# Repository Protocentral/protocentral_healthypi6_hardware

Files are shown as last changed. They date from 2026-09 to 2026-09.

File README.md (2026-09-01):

<div align="center">

<picture>
  <source media="(prefers-color-scheme: dark)" srcset="docs/images/healthypi6-logo-dark.png">
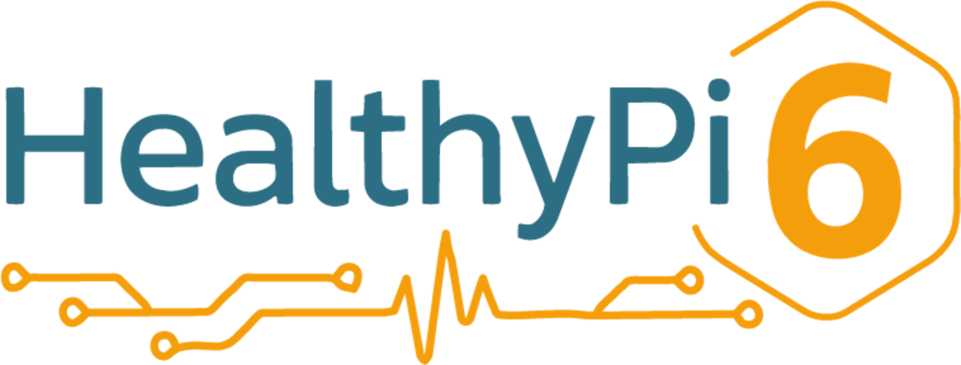
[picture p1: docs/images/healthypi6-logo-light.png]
HealthyPi 6
  
</picture>

</div>

# HealthyPi 6 — Hardware

Open hardware design files for HealthyPi 6, a standalone vital-signs monitor with a
modular expansion bus.

The device is built around a tri-core architecture — an STM32H757BI (Cortex-M7 +
Cortex-M4) with an ESP32-C6 for wireless — with a 4" capacitive touchscreen, an isolated
supply, an isolated USB port, and two HealthyLink expansion slots that accept new sensing
front-ends without a board respin.

This repository holds the KiCad schematics and PCB layouts, the HealthyLink interface
definition, the enclosure CAD, and the CE/UKCA declarations of conformity.

## Links

| | |
|---|---|
| Product page | https://www.crowdsupply.com/protocentral/healthypi-6 |
| Firmware (Zephyr) | https://github.com/Protocentral/healthypi-6-fw |
| HealthyPi Studio | https://github.com/Protocentral/healthypi_studio |

## Boards

Design files are published as each board is finalised.

| Board | Revision | Role |
|---|---|---|
| [`healthypi_6_main_v5`](hardware/healthypi_6_main_v5/) | **v5** | STM32H757BI main board — AFEs, power, wireless, both HealthyLink slots |
| [`healthypi_6_display_v7`](hardware/healthypi_6_display_v7/) | **v7** | Display interface board — MIPI-DSI and touch to the panel, backlight driver |
| [`healthylink_compute_v5`](hardware/healthylink_compute_v5/) | **v5** | HealthyLink compute / NPU module — STM32N657, camera, storage |
| [`healthylink_gpio_v2`](hardware/healthylink_gpio_v2/) | **v2** | HealthyLink GPIO breakout — the minimal module example |

## Specifications

Cross-checked against the v5 schematic in this repository.

- **Application processor:** STM32H757BI (LQFP208) — Arm Cortex-M7 @ 400 MHz +
  Cortex-M4 @ 200 MHz
- **Wireless:** ESP32-C6-MINI-1 (Wi-Fi 6 / BLE / 802.15.4), UART and SPI to the host MCU,
  plus its own USB-C for direct flashing
- **Display:** 4" 480×800 capacitive touchscreen — 2-lane MIPI-DSI, touch on I²C,
  TPS61158 backlight boost on the display board
- **Biosignal front-ends:** TI ADS1294R (ECG + thoracic respiration), TI AFE4400 (PPG),
  Bosch BMI323 (motion)
- **Expansion:** 2 × HealthyLink slots, 2 × Hirose DF9-31P-1V per slot (62 pins/slot),
  per-slot NCP380 current-limited load switch with fault reporting
- **Power:** isolated 10 W supply (Traco THM 10-0511); TI BQ24074 linear battery charger,
  Maxim MAX17048 fuel gauge, TPS62A02 system buck
- **Memory and storage:** 32 MB SDRAM (Winbond W9825G6KH), 64 MB QSPI NOR
  (Winbond W25Q512JV), microSD
- **Host interface:** USB-C, USB 2.0 full-speed, galvanically isolated through a
  TI ISOUSB111
- **Main board:** 120 × 70 mm, 6-layer

## HealthyLink expansion bus

HealthyLink is the modular expansion system for HealthyPi 6. Each slot presents 62 pins
across two Hirose DF9-31 board-to-board connectors, carrying two SPI buses, I²C, a UART,
six analog inputs, CAN, per-slot interrupt and reset, and a switched 3V3 module rail. The
main board has two slots (A and B).

Modules are **not hot-swappable** — install them with the device powered off.

The full pin assignment and electrical definition is in
[`docs/HEALTHYLINK.md`](docs/HEALTHYLINK.md). The KiCad symbol for the connector is
[`hardware/healthylink_df9_connector.kicad_sym`](hardware/healthylink_df9_connector.kicad_sym) —
use it as the starting point for your own module.

## Enclosure

[`enclosure/`](enclosure/) holds the CAD for the case, in three forms: the editable
Fusion archive, a neutral STEP export per part, and a print-ready STL per part.

| Part | Size |
|---|---|
| `top` | 125 × 75 × 23 mm |
| `bottom` | 125 × 75 × 14 mm |
| `back-cover-with-slots` | 125 × 75 × 3 mm |
| `back-cover-no-slots` | 125 × 75 × 7.5 mm |
| `battery-holder` | 53 × 35 × 14 mm |
| `push-switch` | 8 × 5 × 4 mm |
| `slide-switch` | 7 × 13 × 5 mm |

Every part appears under the same name in both
[`enclosure/step/`](enclosure/step/) and [`enclosure/stl/`](enclosure/stl/). The Fusion
source is [`enclosure/source/healthypi6-enclosure-v5.f3z`](enclosure/source/); open it if
you want to change the geometry rather than print it as-is. The enclosure is drawn around
the 120 × 70 mm main board, so any board modification that moves a connector or a mounting
hole needs a matching change here.

## Repository layout

| Path | Contents |
|---|---|
| [`hardware/`](hardware/) | One folder per board: KiCad project (schematic + PCB) and exported schematic PDF |
| [`docs/`](docs/) | HealthyLink interface definition and images |
| [`enclosure/`](enclosure/) | Enclosure CAD — Fusion source, STEP and STL per part |
| [`compliance/`](compliance/) | CE and UKCA declarations of conformity, safety insert |

## Working from these files

- For firmware, start at the firmware repository. This repo is the electrical reference:
  pin assignments, AFE wiring, connector pinouts.
- To build a HealthyLink module, read [`docs/HEALTHYLINK.md`](docs/HEALTHYLINK.md) and
  copy [`healthylink_gpio_v2`](hardware/healthylink_gpio_v2/), which is the minimal
  working example.
- To respin a board: both projects are saved in **KiCad 10** format and will not open in
  earlier versions. Footprints are embedded in the board files and symbols are cached in
  the schematics, so the projects open standalone. A handful of 3D models resolve through
  an internal `${PROTOCENTRAL}` path and will show as missing in the 3D viewer; this
  affects rendering only, never the netlist or the layout.

## Important notice

This device is intended for **research, education, and evaluation use only**. It is **not**
a medical diagnostic instrument, and it is not FDA-approved or otherwise cleared for
clinical or consumer diagnostic use. The CE and UKCA declarations in
[`compliance/`](compliance/) cover EMC and electrical safety for the device as an
electronic product — they are not medical device certifications.

Do not use HealthyPi 6 to make medical decisions.

## License

The hardware design files in this repository are licensed under the **CERN Open Hardware
Licence Version 2 – Permissive (CERN-OHL-P v2)**. See [LICENSE](LICENSE).

Firmware and software for HealthyPi 6 are licensed separately under the MIT License in
their own repositories.

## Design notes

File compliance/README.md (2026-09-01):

# Compliance

| Document | Covers |
|---|---|
| [`healthypi6-ce-doc.pdf`](healthypi6-ce-doc.pdf) | EU Declaration of Conformity |
| [`healthypi6-ukca-doc.pdf`](healthypi6-ukca-doc.pdf) | UKCA Declaration of Conformity |
| [`healthypi6-safety-insert.pdf`](healthypi6-safety-insert.pdf) | A6 safety insert shipped in the box |

These declarations cover HealthyPi 6 as an **electronic product** — EMC and electrical
safety. They are **not** medical device certifications. HealthyPi 6 is not cleared for
clinical or consumer diagnostic use. See the notice in the [top-level README](../README.md).

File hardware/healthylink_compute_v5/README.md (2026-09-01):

# HealthyLink Compute Module

| | |
|---|---|
| Revision | **v5** |
| Role | HealthyLink compute / NPU module — STM32N657 with camera and storage |
| Board | 50 × 60 mm, 6-layer |
| Slot | Occupies one HealthyLink slot (J5) |
| KiCad | 10 |
| Schematic PDF | [`healthylink-compute-v5-schematic.pdf`](healthylink-compute-v5-schematic.pdf) |

## Files

| File | Contents |
|---|---|
| `healthylink_compute_v5.kicad_pro` / `.kicad_sch` / `.kicad_pcb` | KiCad project for this revision |
| `healthylink-compute-v5-schematic.pdf` | Exported schematic — the human-readable reference |

## Schematic sheets

Sheet names and filenames do not line up on this project; the table gives both.

| Sheet | File | Contents |
|---|---|---|
| *(root)* | `healthylink_compute_v5.kicad_sch` | HealthyLink connector, AT24CS02 ID EEPROM, write-protect jumper |
| MCU | `mcu.kicad_sch` | STM32N657I0H3Q, MX25UM51245G octal flash, boot configuration, 32.768 kHz |
| MCU2 | `mcu2.kicad_sch` | 48 MHz oscillator, status LEDs, debug header |
| MCU3 | `power.kicad_sch` | STM32N657 power pins and decoupling |
| power | `sys_power.kicad_sch` | TPS2116 power mux, 3 × TPS62A02 bucks, TLV75518 LDO |
| connectivity | `connectivity.kicad_sch` | microSD, USB-C, MIPI-CSI camera header |

## Bus usage

Of the HealthyLink signals, this module uses `SPI4` (`CS_1`), `I2C3`, `USART2`,
`MOD_IRQ_N`, `MOD_RESET_N` and the stacking bus. See
[`docs/HEALTHYLINK.md`](../../docs/HEALTHYLINK.md) for the full pinout.

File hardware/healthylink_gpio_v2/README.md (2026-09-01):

# HealthyLink GPIO Module

| | |
|---|---|
| Revision | **v2** |
| Role | HealthyLink GPIO breakout — the minimal module example |
| Board | 50 × 62.2 mm, 2-layer |
| Slot | Occupies one HealthyLink slot (J5) |
| KiCad | 10 |
| Schematic PDF | [`healthylink-gpio-v2-schematic.pdf`](healthylink-gpio-v2-schematic.pdf) |

## Files

| File | Contents |
|---|---|
| `healthylink_gpio_v2.kicad_pro` / `.kicad_sch` / `.kicad_pcb` | KiCad project for this revision |
| `healthylink-gpio-v2-schematic.pdf` | Exported schematic — the human-readable reference |

## What it does

A single-sheet board that brings the HealthyLink bus out to two 2×10 headers. It is the
smallest complete module in this repository and the recommended starting point for your
own design: it shows the three things every module needs and nothing else.

- **Connector** — one `HEALTHYLINK_DF9_DUAL` (J5), the two DF9-31 receptacles of one slot
- **Identification** — AT24CS02 EEPROM on `I2C3`, with a write-protect solder jumper
- **Power** — a TPS62A02 buck off the module rail

Both SPI buses, `I2C3`, `USART2`, the six analog inputs, CAN, the stacking bus and the
per-slot interrupt and reset all reach the headers. See
[`docs/HEALTHYLINK.md`](../../docs/HEALTHYLINK.md) for the pinout.

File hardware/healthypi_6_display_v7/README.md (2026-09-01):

# HealthyPi 6 Display Board

| | |
|---|---|
| Revision | **v7** |
| Role | Display interface — routes MIPI-DSI and touch I²C from the main board to the 4" panel, and drives the backlight |
| Board | 60 × 33 mm, 2-layer |
| KiCad | 10 |
| Schematic PDF | [`healthypi6-display-v7-schematic.pdf`](healthypi6-display-v7-schematic.pdf) |

## Files

| File | Contents |
|---|---|
| `healthypi_6_display_v7.kicad_pro` / `.kicad_sch` / `.kicad_pcb` | KiCad project for this revision |
| `healthypi6-display-v7-schematic.pdf` | Exported schematic — the human-readable reference |

## Interfaces

- 24-way FFC to the main board: 2-lane MIPI-DSI, touch I²C (`TP_SCL` / `TP_SDA`,
  `TP_INT`, `TP_RST`), panel reset and tearing-effect (`MIPI_RST`, `MIPI_TE`)
- TPS61158 boost driving the panel backlight, enabled by `MIPI_BKL`
- 12-way connector to the display panel

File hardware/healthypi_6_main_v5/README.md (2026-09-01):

# HealthyPi 6 Main Board

| | |
|---|---|
| Revision | **v5** |
| Role | STM32H757BI host, AFEs, power, wireless, 2 × HealthyLink slots |
| Board | 120 × 70 mm, 6-layer |
| KiCad | 10 |
| Schematic PDF | [`healthypi6-main-v5-schematic.pdf`](healthypi6-main-v5-schematic.pdf) |

## Files

| File | Contents |
|---|---|
| `healthypi_6_v5.kicad_pro` / `.kicad_sch` / `.kicad_pcb` | KiCad project for this revision |
| `healthypi6-main-v5-schematic.pdf` | Exported schematic — the human-readable reference |

## Schematic sheets

| Sheet | File | Contents |
|---|---|---|
| MCU | `mcu.kicad_sch` | STM32H757BI, clocks, SWD, buttons, buzzer |
| ECG Frontend | `ecg_afe.kicad_sch` | TI ADS1294R, ECG input protection |
| PPG Frontend | `ppg_sensor.kicad_sch` | TI AFE4400, Bosch BMI323, DE9 patient connector |
| Memory | `memory.kicad_sch` | SDRAM, QSPI NOR, microSD |
| USB | `io.kicad_sch` | USB-C, ISOUSB111 isolator, isolated 10 W supply |
| Power | `power.kicad_sch` | Battery charger, fuel gauge, system rails |
| Power 2 | `power2.kicad_sch` | Per-slot HealthyLink load switches |
| Wireless | `wireless.kicad_sch` | ESP32-C6-MINI-1 and its USB-C |
| connectors | `connectors.kicad_sch` | Display FFC, front-panel and auxiliary connectors |
| healthylink | `healthylink.kicad_sch` | Both HealthyLink slots — see [`docs/HEALTHYLINK.md`](../../docs/HEALTHYLINK.md) |

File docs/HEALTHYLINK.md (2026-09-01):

<div align="center">

<picture>
  <source media="(prefers-color-scheme: dark)" srcset="images/healthylink-logo-dark.png">
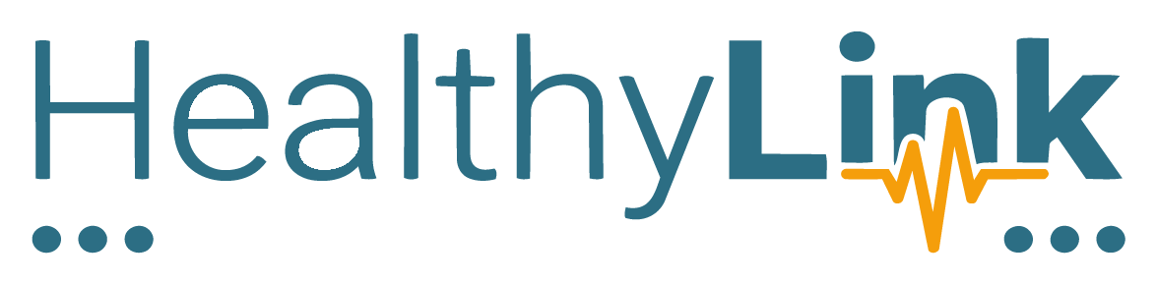
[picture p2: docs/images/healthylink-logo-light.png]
HealthyLink
  
</picture>

</div>

# HealthyLink — Interface Definition

HealthyLink is the modular expansion bus on HealthyPi 6. It lets the device gain new
sensing front-ends — EEG, compute, GPIO, your own — without respinning the main board.

Everything below is taken from the **v5 main board** schematic in this repository, which
is the shipping host design.

## Electrical overview

| | |
|---|---|
| Connector | Hirose **DF9-31P-1V(32)**, 2 per slot (Primary + Secondary) |
| Pins per slot | 62 |
| Slots on main board | 2 (Slot A, Slot B) |
| Module rail | Switched 3V3 per slot (`VDD_MOD`) through an NCP380 current-limited load switch |
| Always-on rail | `VDD_MOD_AON`, present whenever the device is powered |
| Rail control | Host-side `LDO_EN_MOD_A` / `LDO_EN_MOD_B`; fault flags `MOD_A_FLT` / `MOD_B_FLT` |
| Per-slot interrupt | `MOD_IRQ_N` — `MOD_IRQ_A` / `MOD_IRQ_B` on the host |
| Per-slot reset | `MOD_RESET_N` — `MOD_RESET_A` / `MOD_RESET_B` on the host |
| Module identification | I²C EEPROM on `I2C3`, read during a power-sequenced bus scan |
| Hot-swap | **Not supported.** Install modules with the device powered off. |

Both slots share `SPI4`, `SPI6`, `I2C3`, `USART2`, the analog inputs, the stacking bus and
CAN. Only the interrupt, reset and rail control are per-slot.

## Pinout

Directions are given **from the host's point of view**. Each slot is two DF9-31
connectors: pins 1–31 on the Primary, pins 32–62 on the Secondary.

### Primary connector (pins 1–31)

| Pin | Signal | Direction | Notes |
|---:|---|---|---|
| 1 | `VDD_MOD` | Power | Switched 3V3 module rail |
| 2 | `VDD_MOD` | Power | |
| 3 | `VDD_MOD` | Power | |
| 4 | `VDD_MOD` | Power | |
| 5 | `SPI4_SCK` | Host → Module | Primary SPI bus |
| 6 | `GND` | Power | |
| 7 | `SPI4_MOSI` | Host → Module | |
| 8 | `GND` | Power | |
| 9 | `SPI4_MISO` | Module → Host | |
| 10 | `GND` | Power | |
| 11 | `SPI4_CS_1` | Host → Module | Chip select 1 |
| 12 | `RSVD` | — | Reserved, do not connect |
| 13 | `SPI4_CS_2` | Host → Module | Chip select 2 |
| 14 | `RSVD` | — | Reserved, do not connect |
| 15 | `I2C3_SCL` | Bidirectional | Module ID EEPROM and module I²C devices |
| 16 | `RSVD` | — | Reserved, do not connect |
| 17 | `I2C3_SDA` | Bidirectional | |
| 18 | `RSVD` | — | Reserved, do not connect |
| 19 | `USART2_TX` | Host → Module | |
| 20 | `AGND` | Power | Analog ground |
| 21 | `USART2_RX` | Module → Host | |
| 22 | `AGND` | Power | |
| 23 | `USART2_RTS` | Host → Module | |
| 24 | `AGND` | Power | |
| 25 | `USART2_CTS` | Module → Host | |
| 26 | `AGND` | Power | |
| 27 | `MOD_IRQ_N` | Module → Host | Per-slot interrupt, active low |
| 28 | `VDD_MOD_AON` | Power | Always-on module rail |
| 29 | `MOD_RESET_N` | Host → Module | Per-slot reset, active low |
| 30 | `GND` | Power | |
| 31 | `GND` | Power | |

### Secondary connector (pins 32–62)

| Pin | Signal | Direction | Notes |
|---:|---|---|---|
| 32 | `VDD_MOD` | Power | |
| 33 | `GND` | Power | |
| 34 | `VDD_MOD` | Power | |
| 35 | `GND` | Power | |
| 36 | `SPI6_SCK` | Host → Module | Secondary SPI bus |
| 37 | `GND` | Power | |
| 38 | `SPI6_MOSI` | Host → Module | |
| 39 | `GND` | Power | |
| 40 | `SPI6_MISO` | Module → Host | |
| 41 | `GND` | Power | |
| 42 | `SPI6_CS_1` | Host → Module | Chip select 1 |
| 43 | `RSVD` | — | Reserved, do not connect |
| 44 | `SPI6_CS_2` | Host → Module | Chip select 2 |
| 45 | `STACK_SCK` | Module ↔ Module | Stacking bus, not driven by the host |
| 46 | `HL_ADC_CH0` | Module → Host | Analog input |
| 47 | `STACK_MOSI` | Module ↔ Module | |
| 48 | `HL_ADC_CH1` | Module → Host | |
| 49 | `STACK_MISO` | Module ↔ Module | |
| 50 | `HL_ADC_CH2` | Module → Host | |
| 51 | `STACK_CS` | Module ↔ Module | |
| 52 | `HL_ADC_CH3` | Module → Host | |
| 53 | `MOD_ADDR` | Module → Host | Module address strap |
| 54 | `HL_ADC_CH4` | Module → Host | |
| 55 | `AUX_GPIO0` | Bidirectional | General-purpose |
| 56 | `HL_ADC_CH5` | Module → Host | |
| 57 | `AUX_GPIO1` | Bidirectional | |
| 58 | `FDCAN1_TX` | Host → Module | |
| 59 | `AUX_GPIO2` | Bidirectional | |
| 60 | `FDCAN1_RX` | Module → Host | |
| 61 | `NC` | — | Not connected |
| 62 | `GND` | Power | |

The connector shells carry mounting pins (`MP`) which are tied to ground on the main board.

## Power sequencing

A slot's `VDD_MOD` rail comes up only when the host asserts that slot's enable
(`LDO_EN_MOD_A` / `LDO_EN_MOD_B`). The load switch reports over-current back to the host on
`MOD_A_FLT` / `MOD_B_FLT`, so a shorted module is detected and the slot stays down.

`VDD_MOD_AON` is not switched. Draw only what a module needs to stay identifiable while
its main rail is off.

## Module identification

Modules are identified by an **EEPROM on I²C3**, not by strapping GPIOs. The host powers a
slot, scans the bus, reads the module's identity from its EEPROM, and loads the matching
driver. Earlier designs used dedicated `MOD_ID` pins; those were freed, and the EEPROM is
now the identification path.

## Reference modules

| Module | What it adds |
|---|---|
| [`healthylink_gpio_v2`](../hardware/healthylink_gpio_v2/) | Plain GPIO breakout — the minimal example |
| [`healthylink_compute_v5`](../hardware/healthylink_compute_v5/) | STM32N657 compute / NPU module with camera and storage |

## Building your own module

1. Start from [`healthylink_gpio_v2`](../hardware/healthylink_gpio_v2/) — the smallest
   complete module in this repo — or use the connector symbol at
   [`hardware/healthylink_df9_connector.kicad_sym`](../hardware/healthylink_df9_connector.kicad_sym),
   which carries a host and a module variant, both matching the pinout above.
2. Fit an I²C EEPROM and program it with your module's identity, or the host will not
   enumerate your board.
3. Respect the switched rail: your module must tolerate `VDD_MOD` being held off at boot,
   and must not back-feed the bus from `VDD_MOD_AON`.
4. Stay inside the slot's current limit — the load switch will trip and drop the slot.
5. Leave `RSVD` and `NC` pins unconnected.

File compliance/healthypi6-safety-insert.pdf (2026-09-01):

# HEALTHYPI 6

## KIT & BOARDS

Safety & Regulatory Information

Sicherheits- und Konformitätsinformationen

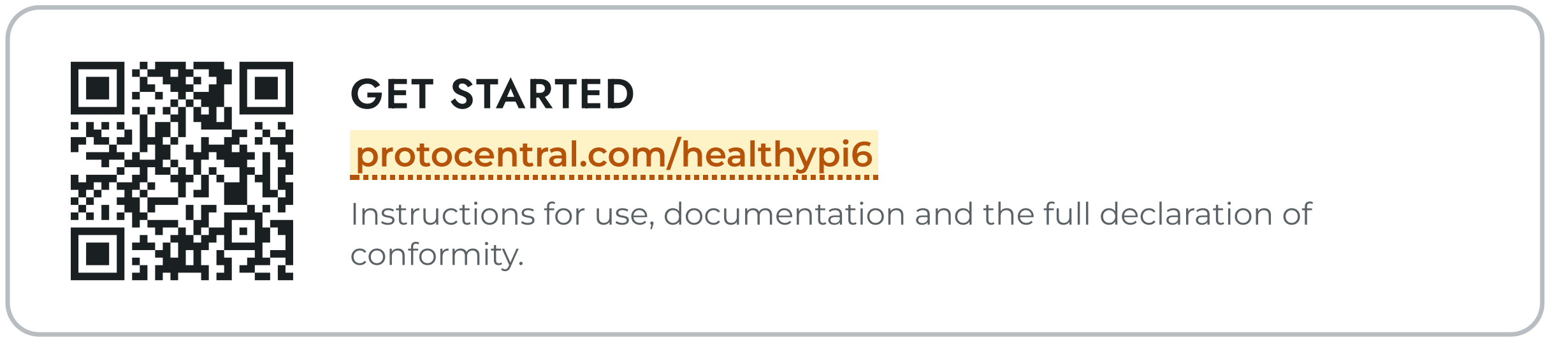
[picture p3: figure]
GET STARTED; protocentral.com/healthypi6; conformity.

Instructions for use, documentation and the full declaration of

English — p. 2 | Deutsch — S. 5
Retain for future reference · Zum Nachschlagen aufbewahren | 1

HEALTHYPI 6 · SAFETY | EN

Hello and welcome to HealthyPi! Before using this device, please read the

instructions for use and important safety information at the locations shown

on the front page. Retain this information in a safe place for future reference.

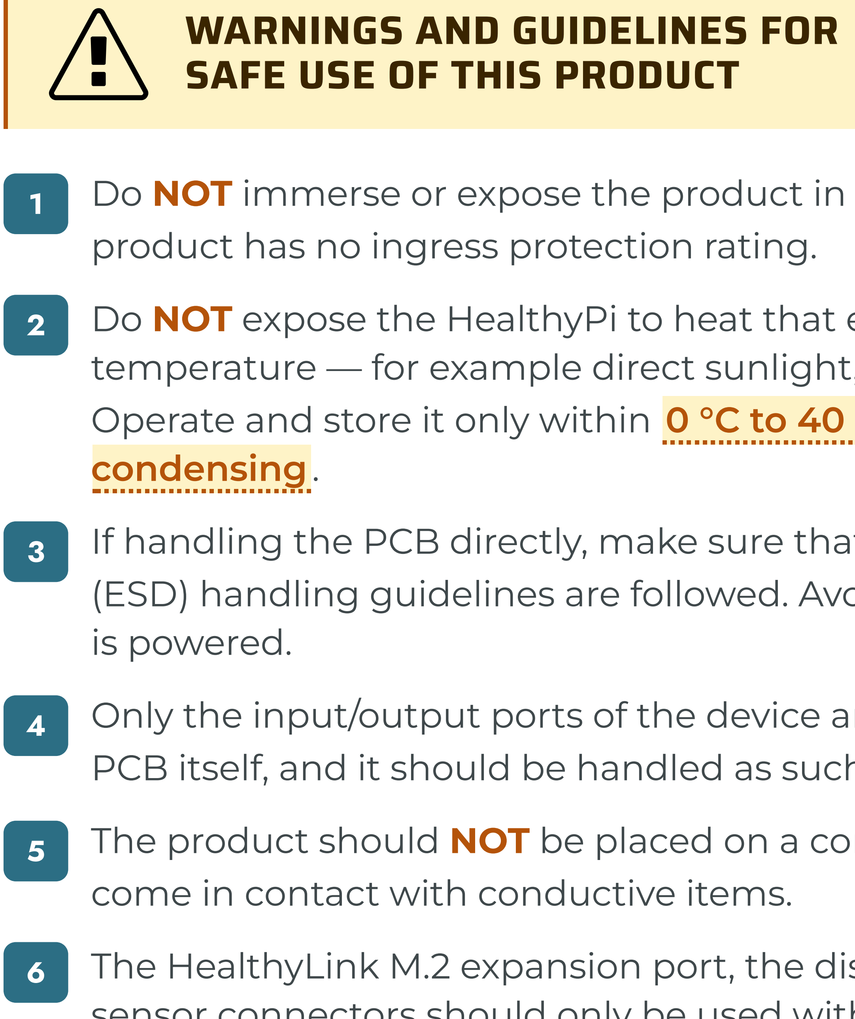
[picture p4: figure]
WARNINGS AND GUIDELINES FOR; SAFE USE OF THIS PRODUCT; condensing.; is powered.; come in contact with conductive items.

Warnings continue overleaf | 2

Do NOT immerse or expose the product in water or any other liquid. The

product has no ingress protection rating.

Do NOT expose the HealthyPi to heat that exceeds ambient room

temperature — for example direct sunlight, a heater, or a closed vehicle.

Operate and store it only within | 0 °C to 40 °C | and | up to 85 % RH, non-

If handling the PCB directly, make sure that all Electrostatic Discharge

(ESD) handling guidelines are followed. Avoid touching the PCB when it

Only the input/output ports of the device are ESD protected and not the

PCB itself, and it should be handled as such.

The product should NOT be placed on a conductive surface, nor should it

The HealthyLink M.2 expansion port, the display connector and the

sensor connectors should only be used with compatible ProtoCentral

accessories. Improper use of the pins can result in permanent damage to

the circuits. Always insert or remove an expansion module with the

device powered off.

HEALTHYPI 6 · SAFETY | EN

## WARNINGS AND GUIDELINES (CONTINUED)

Regulatory information overleaf | 3

Use only the ECG patient cable supplied with the product, together with

commercially available single-use ECG electrodes. Do not apply

electrodes to broken or irritated skin, and do not reuse single-use

electrodes.

7

To ensure compliance with the tested parameters, power the HealthyPi

only from a certified USB-C power adapter capable of providing at least

1.5 A at 5 V.

8

The product contains a rechargeable lithium-polymer battery. Do NOT

puncture, crush, disassemble, short-circuit, incinerate, or heat the battery

above 45 °C. Charge it only through the device's USB-C port. Replace it

only with a type supplied by ProtoCentral. Stop using the product if the

battery swells, leaks, or overheats.

9

Although this product is capable of acquisition of biosignals with high

accuracy, it is NOT a medical device. It is intended for education, research

and development only, and shall not be used for diagnosis, treatment, or

any clinical decision.

10

To reduce the risk of electric shock, do NOT connect the electrodes from

the device to the body while the device is connected to a mains-derived

power supply. When electrodes are attached to a body, run the device on

its internal battery or from a properly isolated supply.

11

Do not use the product in explosive atmospheres or in any environment

where radio transmission is prohibited.

12

HEALTHYPI 6 · REGULATORY | EN

## REGULATORY AND

## COMPLIANCE INFORMATION

## EU DECLARATION OF CONFORMITY

Hereby, Protocentral Electronics Pvt. Ltd. declares that the radio equipment

type HealthyPi 6 is in compliance with Directive 2014/53/EU. The full text of

the EU declaration of conformity is available at the following internet address:

https://protocentral.com/healthypi6/doc

The product is also in compliance with Directive 2011/65/EU as amended by

Directive (EU) 2015/863 (RoHS), and with Regulation (EU) 2023/1542 (Batteries).

## RADIO PARAMETERS — RED ART. 10(8)

RADIO | FREQUENCY BAND | MAX. POWER

Wi-Fi 2.4 GHz

802.11 b/g/n/ax

2400–2483.5

## MHz

## ≤ 20 dBm EIRP

Bluetooth LE 5.3 | 2400–2483.5

## MHz

## ≤ 10 dBm EIRP

IEEE 802.15.4

where enabled

2400–2483.5

## MHz

## ≤ 20 dBm EIRP

## EMISSIONS & RF EXPOSURE

This product has been tested and found to be in compliance with the RF

emission limits for Class B Information Technology Equipment standard of

the EU and the UK. It complies with the applicable European limits for human

exposure to electromagnetic fields (EN 62479 / EN 50665) and may be

operated in contact with the body.

## DISPOSAL

This product and the battery contained in this product shall be disposed of

separately from household waste. Please dispose in accordance with local

environmental laws and guidelines. The battery is user-replaceable by

removing the rear enclosure screws and disconnecting the battery lead;

remove it before disposing of the product.

Marks and addresses on p. 8 | 4

HEALTHYPI 6 · SICHERHEIT | DE

Hallo und willkommen bei HealthyPi! Bevor Sie dieses Gerät verwenden, lesen

Sie bitte die Gebrauchsanweisung und die wichtigen

Sicherheitsinformationen an den auf der Titelseite genannten Stellen.

Bewahren Sie diese Informationen zum späteren Nachschlagen an einem

sicheren Ort auf.

WARNUNGEN UND RICHTLINIEN FÜR DIE

SICHERE VERWENDUNG DIESES PRODUKTS

Fortsetzung auf der nächsten Seite | 5

Tauchen Sie das Produkt NICHT in Wasser oder andere Flüssigkeiten und

setzen Sie es keiner Nässe aus. Das Produkt besitzt keine Schutzart

gegen das Eindringen von Wasser.

1

Setzen Sie den HealthyPi KEINER Hitze über Raumtemperatur aus — z.

B. direkter Sonneneinstrahlung, Heizkörpern oder einem geschlossenen
Fahrzeug. Betreiben und lagern Sie das Gerät nur bei | 0 °C bis 40 °C | und

bis zu 85 % rel. Luftfeuchte, nicht kondensierend.

2

Stellen Sie beim direkten Umgang mit der Leiterplatte sicher, dass alle

Richtlinien zum Umgang mit elektrostatischer Entladung (ESD) befolgt

werden. Vermeiden Sie es, die Leiterplatte zu berühren, wenn sie mit

Strom versorgt wird.

3

Nur die Ein- und Ausgänge des Geräts sind ESD-geschützt, nicht die

Leiterplatte selbst; sie ist entsprechend zu behandeln.

4

Das Produkt darf NICHT auf eine leitfähige Oberfläche gelegt werden

und nicht mit leitfähigen Gegenständen in Berührung kommen.

5

Der HealthyLink-M.2-Erweiterungsanschluss, der Displayanschluss und

die Sensoranschlüsse dürfen nur mit kompatiblem ProtoCentral-Zubehör

verwendet werden. Eine unsachgemäße Verwendung der Kontakte kann

zu dauerhaften Schäden an den Schaltkreisen führen. Stecken oder

entfernen Sie Erweiterungsmodule ausschließlich bei ausgeschaltetem

Gerät.

6

HEALTHYPI 6 · SICHERHEIT | DE

## WARNUNGEN UND RICHTLINIEN (FORTSETZUNG)

Vorschriften auf der nächsten Seite | 6

Verwenden Sie ausschließlich das mitgelieferte EKG-Patientenkabel

zusammen mit handelsüblichen EKG-Einmalelektroden. Bringen Sie

Elektroden nicht auf verletzter oder gereizter Haut an und verwenden

Sie Einmalelektroden nicht mehrfach.

7

Um die Einhaltung der geprüften Parameter sicherzustellen, betreiben

Sie den HealthyPi nur über ein zertifiziertes USB-C-Netzteil, das

mindestens | 1,5 A | bei 5 V liefern kann.

8

Das Produkt enthält einen wiederaufladbaren Lithium-Polymer-Akku.

Der Akku darf NICHT durchstochen, gequetscht, zerlegt,

kurzgeschlossen, verbrannt oder über | 45 °C | hinaus erwärmt werden.

Laden Sie ihn ausschließlich über den USB-C-Anschluss des Geräts.

Ersetzen Sie ihn nur durch einen von ProtoCentral gelieferten Typ.

Verwenden Sie das Produkt nicht weiter, wenn der Akku sich aufbläht,

ausläuft oder überhitzt.

9

Obwohl dieses Produkt Biosignale mit hoher Genauigkeit erfassen kann,

ist es KEIN Medizinprodukt. Es ist ausschließlich für Ausbildung,

Forschung und Entwicklung bestimmt und darf nicht zur Diagnose, zur

Behandlung oder für klinische Entscheidungen verwendet werden.

10

Um das Risiko eines Stromschlags zu verringern, verbinden Sie die

Elektroden des Geräts NICHT mit dem Körper, während das Gerät an

eine netzgespeiste Stromversorgung angeschlossen ist. Betreiben Sie

das Gerät über den internen Akku oder über eine ordnungsgemäß

galvanisch getrennte Stromversorgung, solange Elektroden am Körper

angebracht sind.

11

Verwenden Sie das Produkt nicht in explosionsgefährdeten Bereichen

oder in Umgebungen, in denen Funkübertragungen untersagt sind.

12

HEALTHYPI 6 · VORSCHRIFTEN | DE

## INFORMATIONEN ZU

## VORSCHRIFTEN UND COMPLIANCE

## EU-KONFORMITÄTSERKLÄRUNG

Hiermit erklärt Protocentral Electronics Pvt. Ltd., dass der Funkanlagentyp

HealthyPi 6 der Richtlinie 2014/53/EU entspricht. Der vollständige Text der

EU-Konformitätserklärung ist unter der folgenden Internetadresse verfügbar:

https://protocentral.com/healthypi6/doc

Das Produkt entspricht ferner der Richtlinie 2011/65/EU, geändert durch die

Richtlinie (EU) 2015/863 (RoHS), sowie der Verordnung (EU) 2023/1542

(Batterien).

## FUNKPARAMETER — RED ART. 10 ABS. 8

FUNKSCHNITTSTELLE | FREQUENZBAND | MAX. LEISTUNG

WLAN 2,4 GHz

802.11 b/g/n/ax

2400–2483,5

## MHz

## ≤ 20 dBm EIRP

Bluetooth LE 5.3 | 2400–2483,5

## MHz

## ≤ 10 dBm EIRP

IEEE 802.15.4

sofern aktiviert

2400–2483,5

## MHz

## ≤ 20 dBm EIRP

## STÖRAUSSENDUNG & EMF-EXPOSITION

Dieses Produkt wurde geprüft und entspricht den HF-Emissionsgrenzwerten

für Informationstechnologiegeräte der Klasse B der EU und des Vereinigten

Königreichs. Es hält die geltenden europäischen Grenzwerte für die

Exposition von Personen gegenüber elektromagnetischen Feldern (EN 62479

/ EN 50665) ein und darf am Körper getragen betrieben werden.

## ENTSORGUNG

Dieses Produkt und der darin enthaltene Akku müssen getrennt vom

Hausmüll entsorgt werden. Bitte entsorgen Sie sie gemäß den örtlichen

Umweltgesetzen und -richtlinien. Der Akku ist durch den Nutzer entnehmbar

— Gehäuseschrauben auf der Rückseite lösen und die Akkuleitung

abziehen; nehmen Sie ihn vor der Entsorgung des Produkts heraus.

Kennzeichnung und Anschriften auf S. 8 | 7

HEALTHYPI 6 | EN / DE

Dispose of separately from

household waste.

Getrennt vom Hausmüll

entsorgen.

### MANUFACTURER / HERSTELLER

Protocentral Electronics Pvt. Ltd.

526, 2nd Floor, 7th Cross, 10th Main, Jeevanbhima Nagar,

HAL 3rd Stage, Bengaluru 560075, India

support@protocentral.com

### EU AUTHORISED REPRESENTATIVE / IMPORTER BEVOLLMÄCHTIGTER / EINFÜHRER IN DER EU

Name · Straße · PLZ Ort · Land · E-Mail

### UK RESPONSIBLE PERSON VERANTWORTLICHE PERSON IM VEREINIGTEN KÖNIGREICH

Name · Street · Postcode City · United Kingdom · e-mail

### NOT A MEDICAL DEVICE KEIN MEDIZINPRODUKT

For education, research and development only.

Nur für Ausbildung, Forschung und Entwicklung.

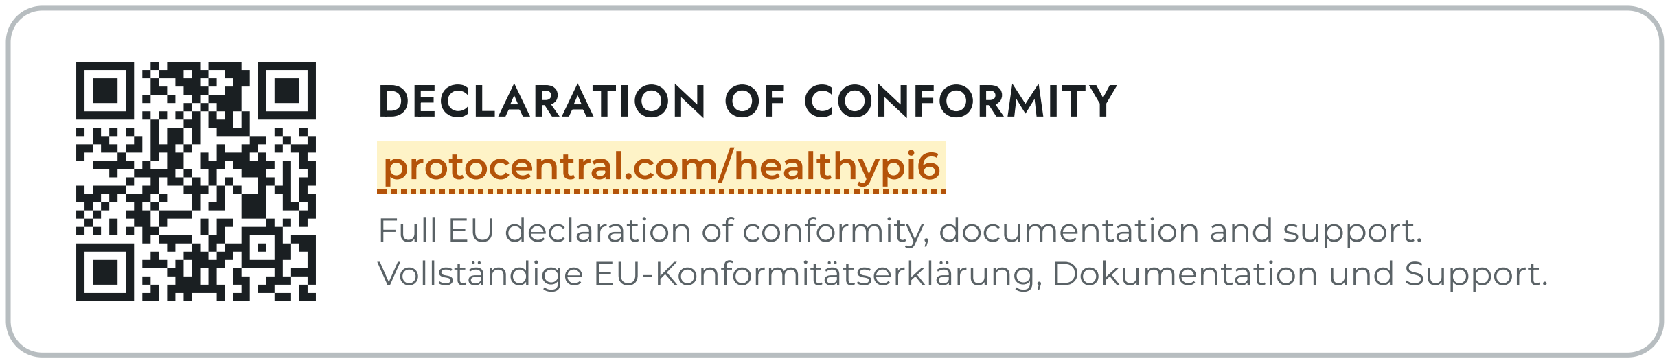
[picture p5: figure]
DECLARATION OF CONFORMITY; protocentral.com/healthypi6; Vollständige EU-Konformitätserklärung, Dokumentation und Support.

Full EU declaration of conformity, documentation and support.

Doc. | HP6-SAF-001 | · Rev. | A | · | 2026-07 | 8

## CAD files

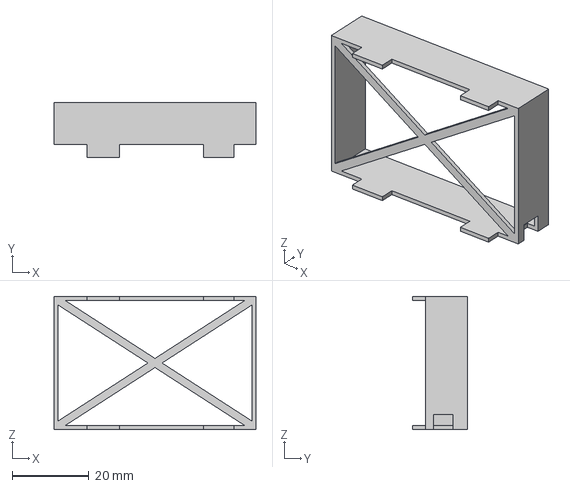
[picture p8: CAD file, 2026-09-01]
enclosure/step/battery-holder.step
52.8 x 14.4 x 34.8 mm

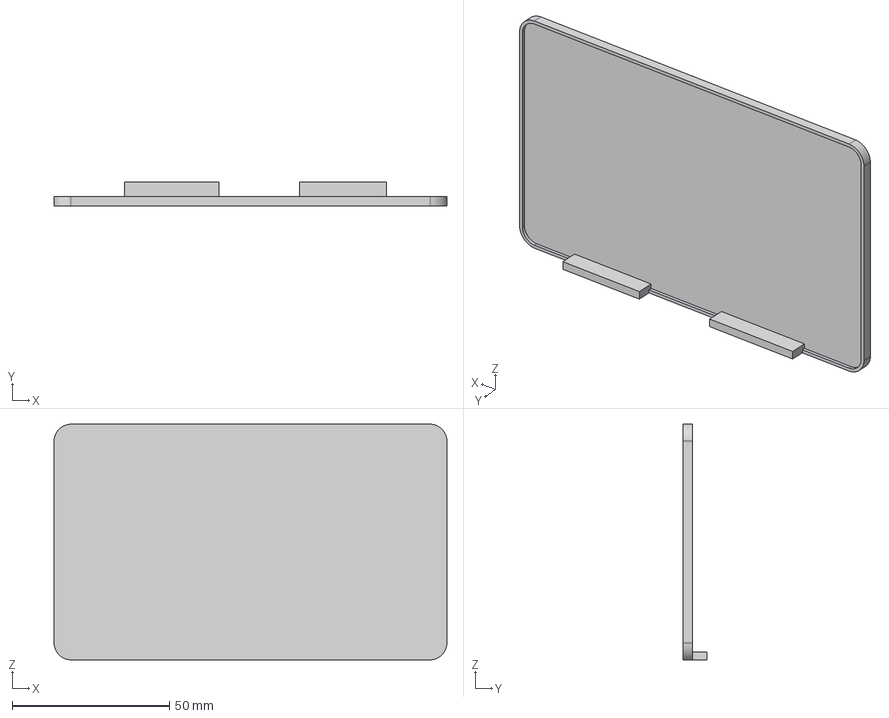
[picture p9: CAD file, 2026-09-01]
enclosure/step/back-cover-no-slots.step
125.0 x 7.50 x 75.0 mm

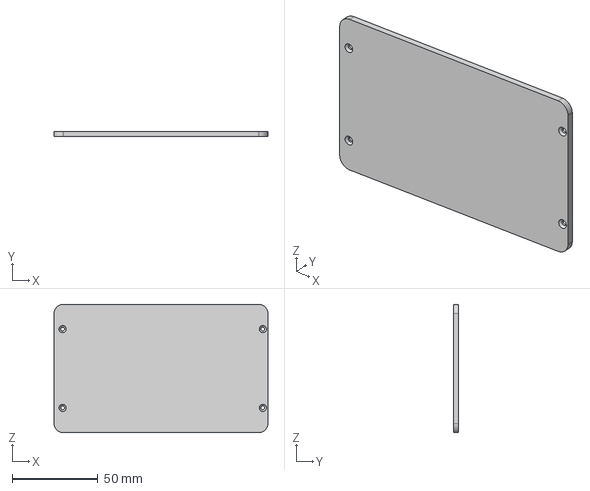
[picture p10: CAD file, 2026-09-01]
enclosure/step/back-cover-with-slots.step
125.0 x 3.00 x 75.0 mm

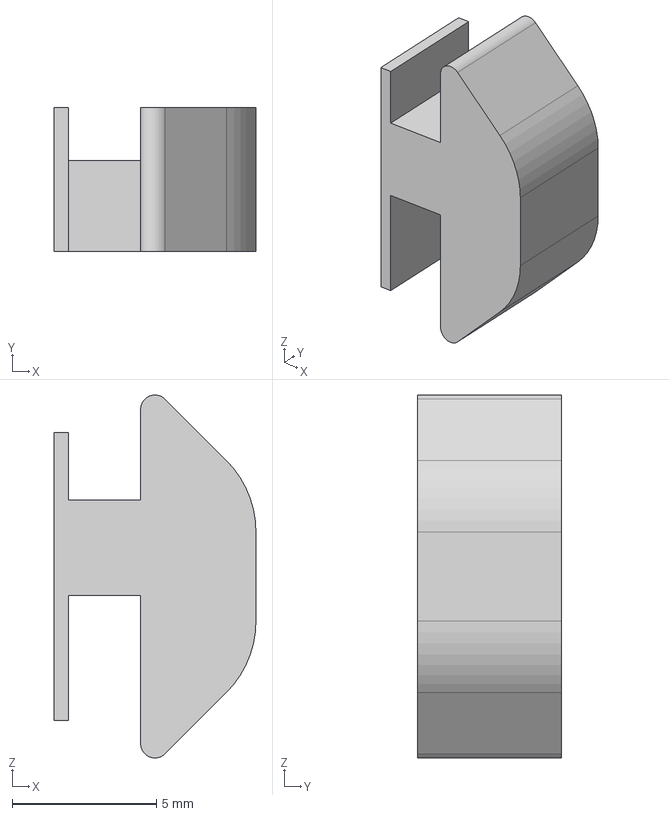
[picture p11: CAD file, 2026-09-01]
enclosure/step/slide-switch.step
7.00 x 5.00 x 12.6 mm

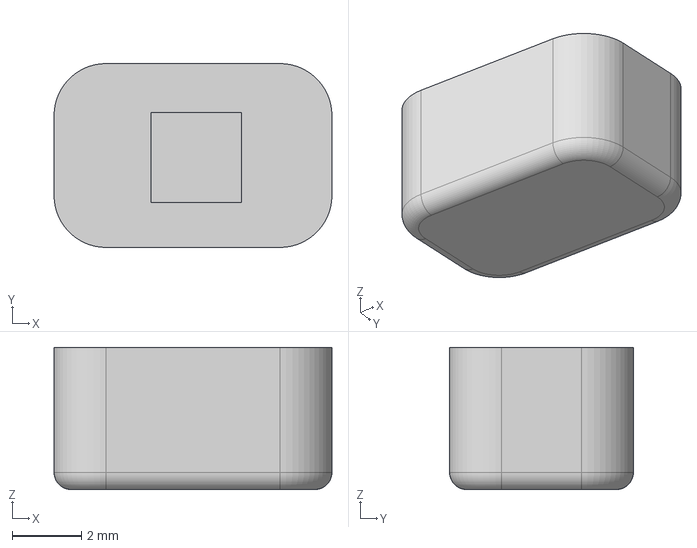
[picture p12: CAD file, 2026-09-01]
enclosure/step/push-switch.step
8.02 x 5.30 x 4.10 mm

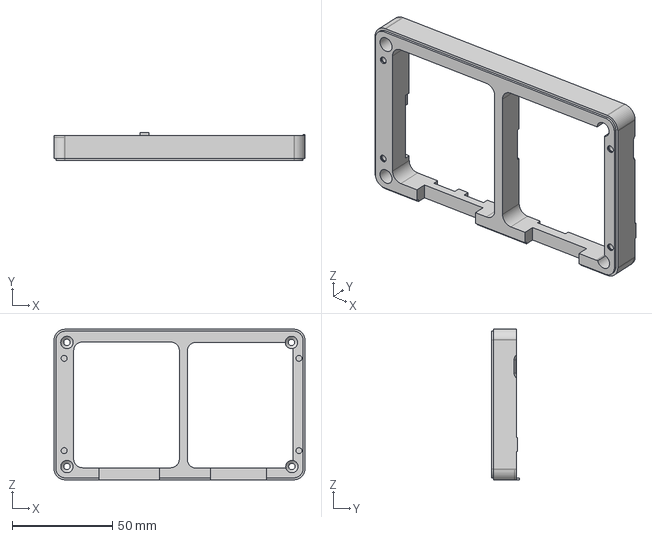
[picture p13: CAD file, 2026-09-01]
enclosure/step/bottom.step
125.0 x 14.0 x 75.0 mm

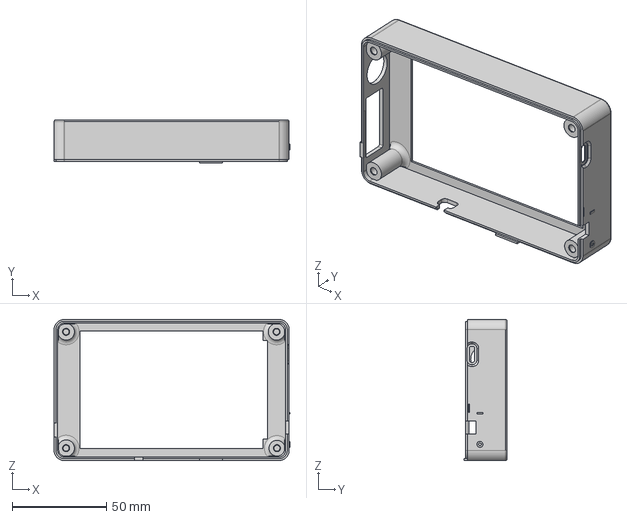
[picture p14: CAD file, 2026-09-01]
enclosure/step/top.step
125.4 x 23.0 x 75.0 mm

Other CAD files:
enclosure/stl/back-cover-no-slots.stl
enclosure/stl/back-cover-with-slots.stl
enclosure/stl/battery-holder.stl
enclosure/stl/bottom.stl
enclosure/stl/push-switch.stl
enclosure/stl/slide-switch.stl
enclosure/stl/top.stl

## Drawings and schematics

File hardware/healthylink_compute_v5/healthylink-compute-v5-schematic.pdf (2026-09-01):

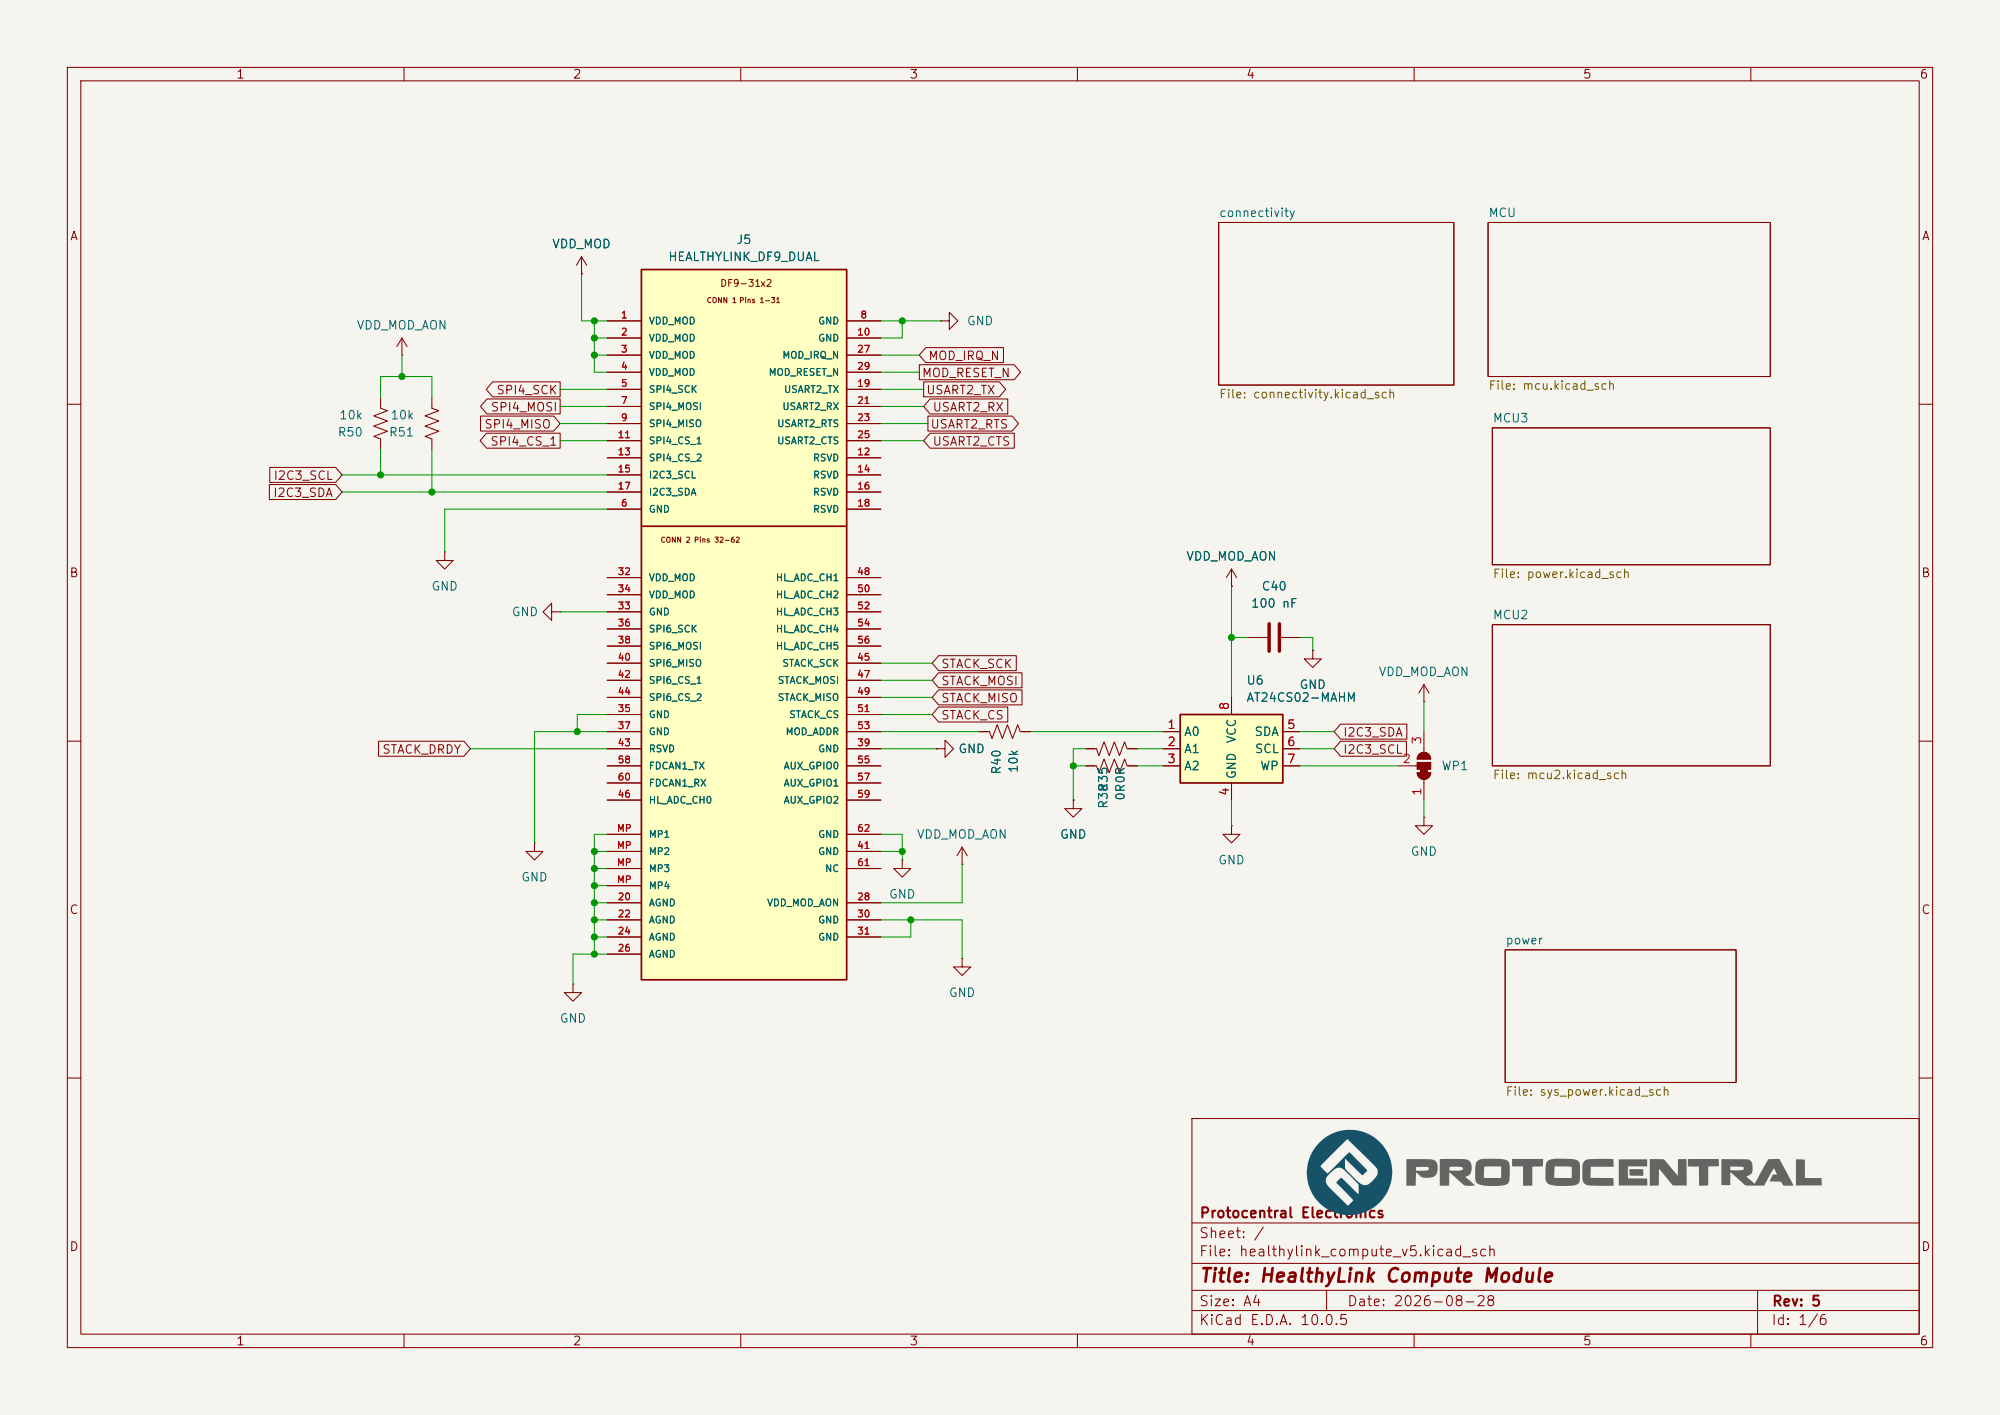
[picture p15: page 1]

Protocentral Electronics
Sheet: /
File: healthylink_compute_v5.kicad_sch
Title: HealthyLink Compute Module

Size: A4 | Rev: 5
KiCad E.D.A. 10.0.5 | Id: 1/6

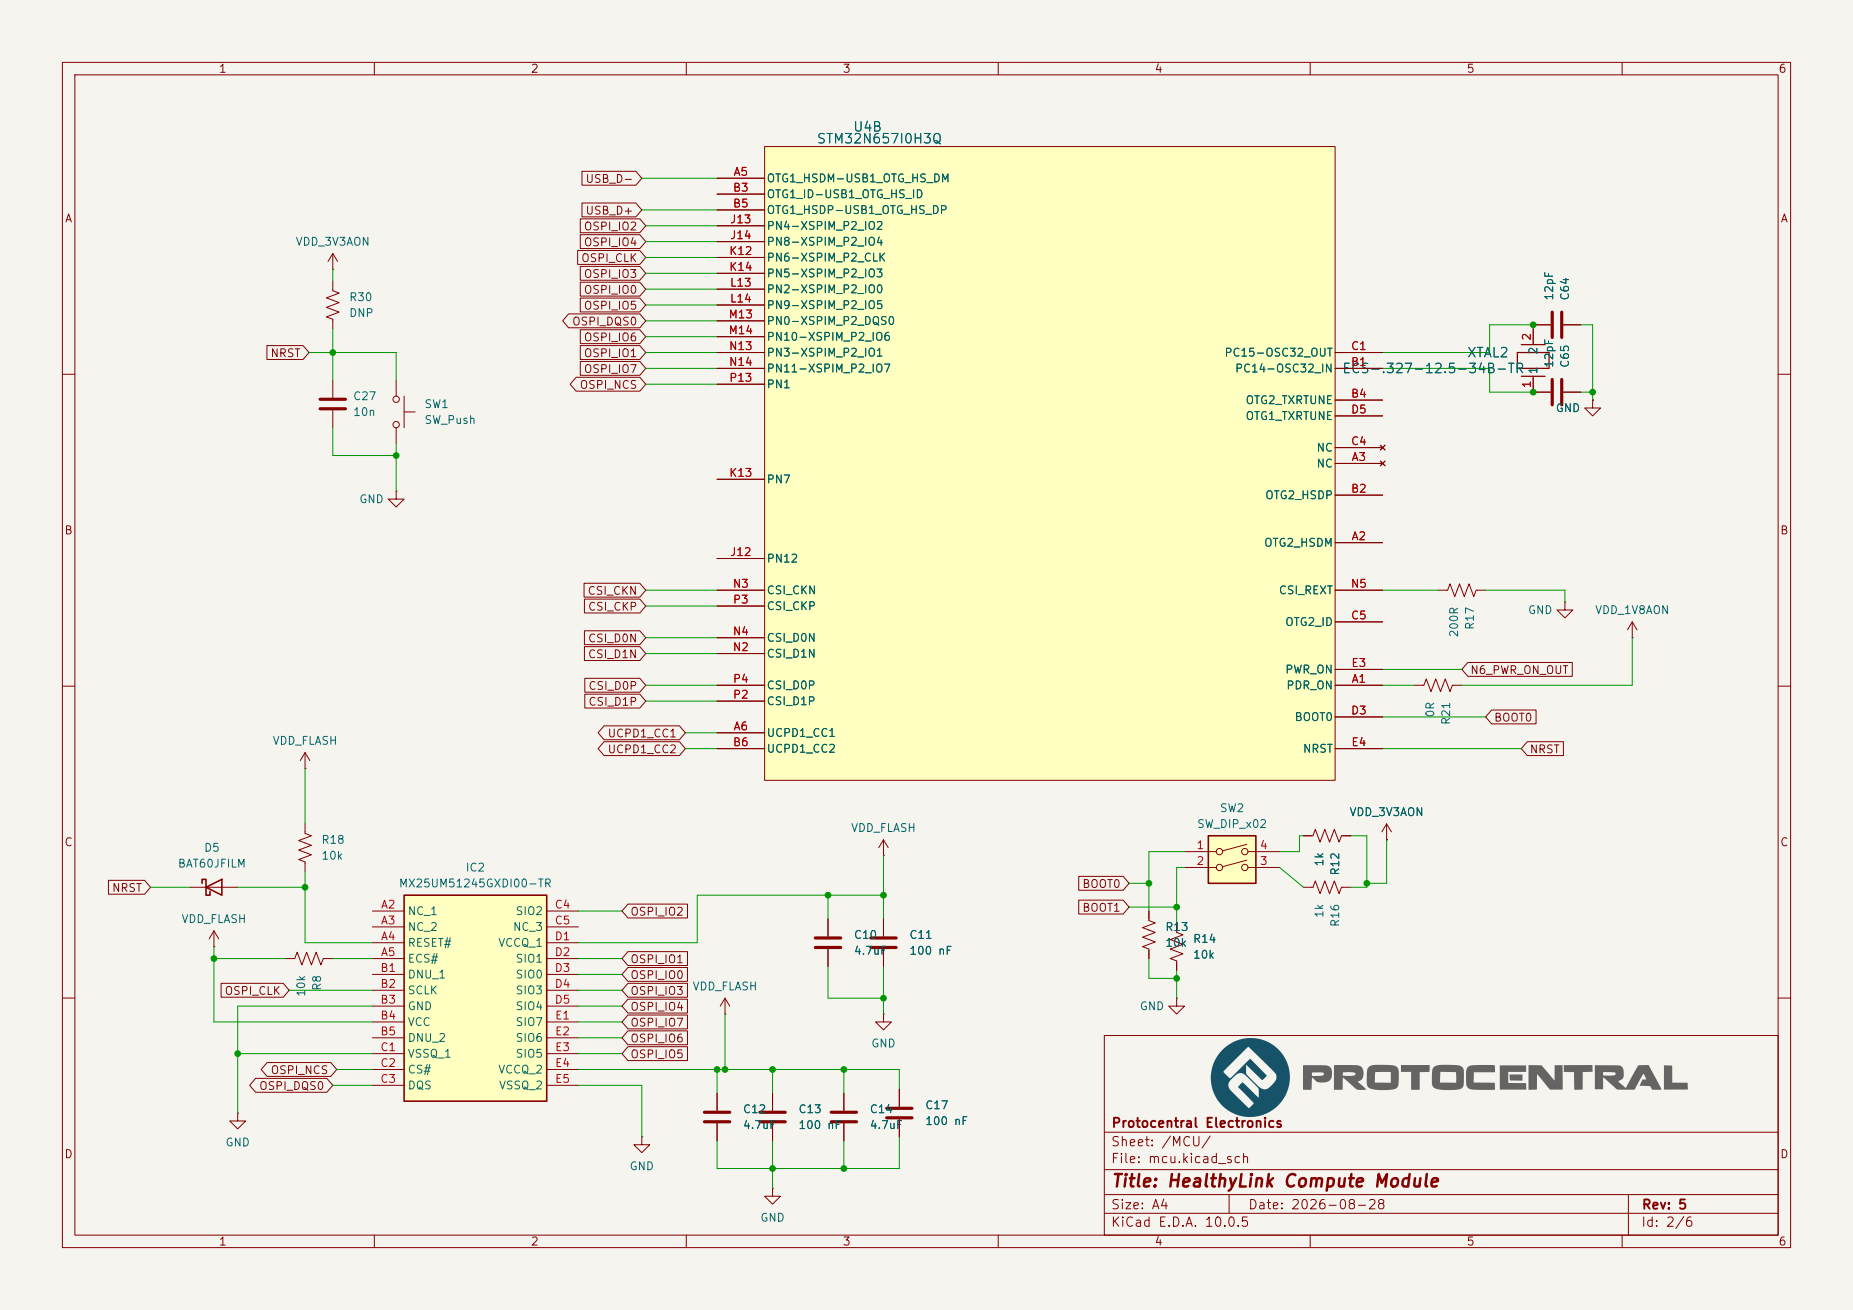
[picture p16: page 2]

Sheet: /MCU/
File: mcu.kicad_sch
Title: HealthyLink Compute Module

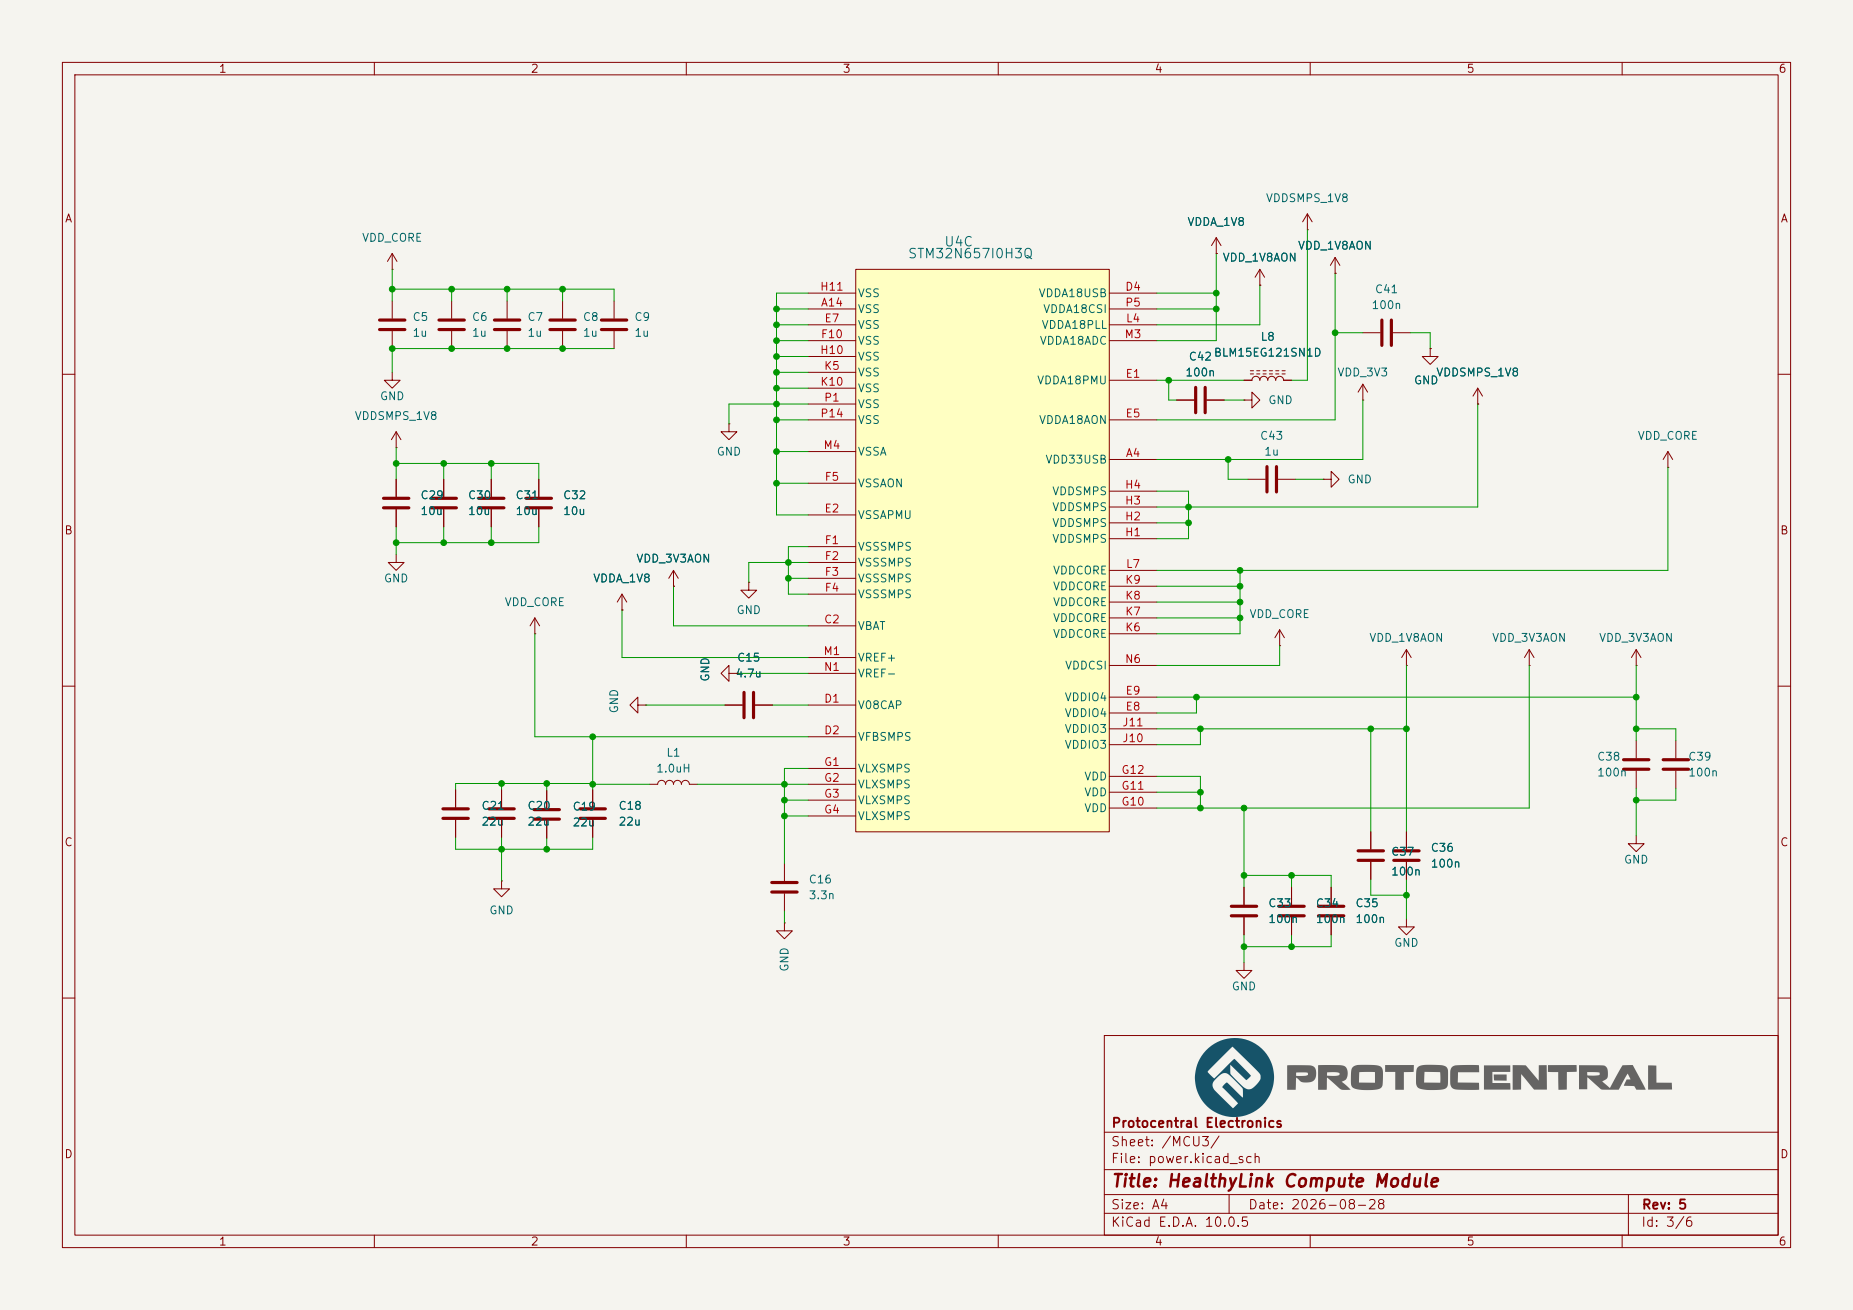
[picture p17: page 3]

Protocentral Electronics
Sheet: /MCU3/
File: power.kicad_sch
Title: HealthyLink Compute Module

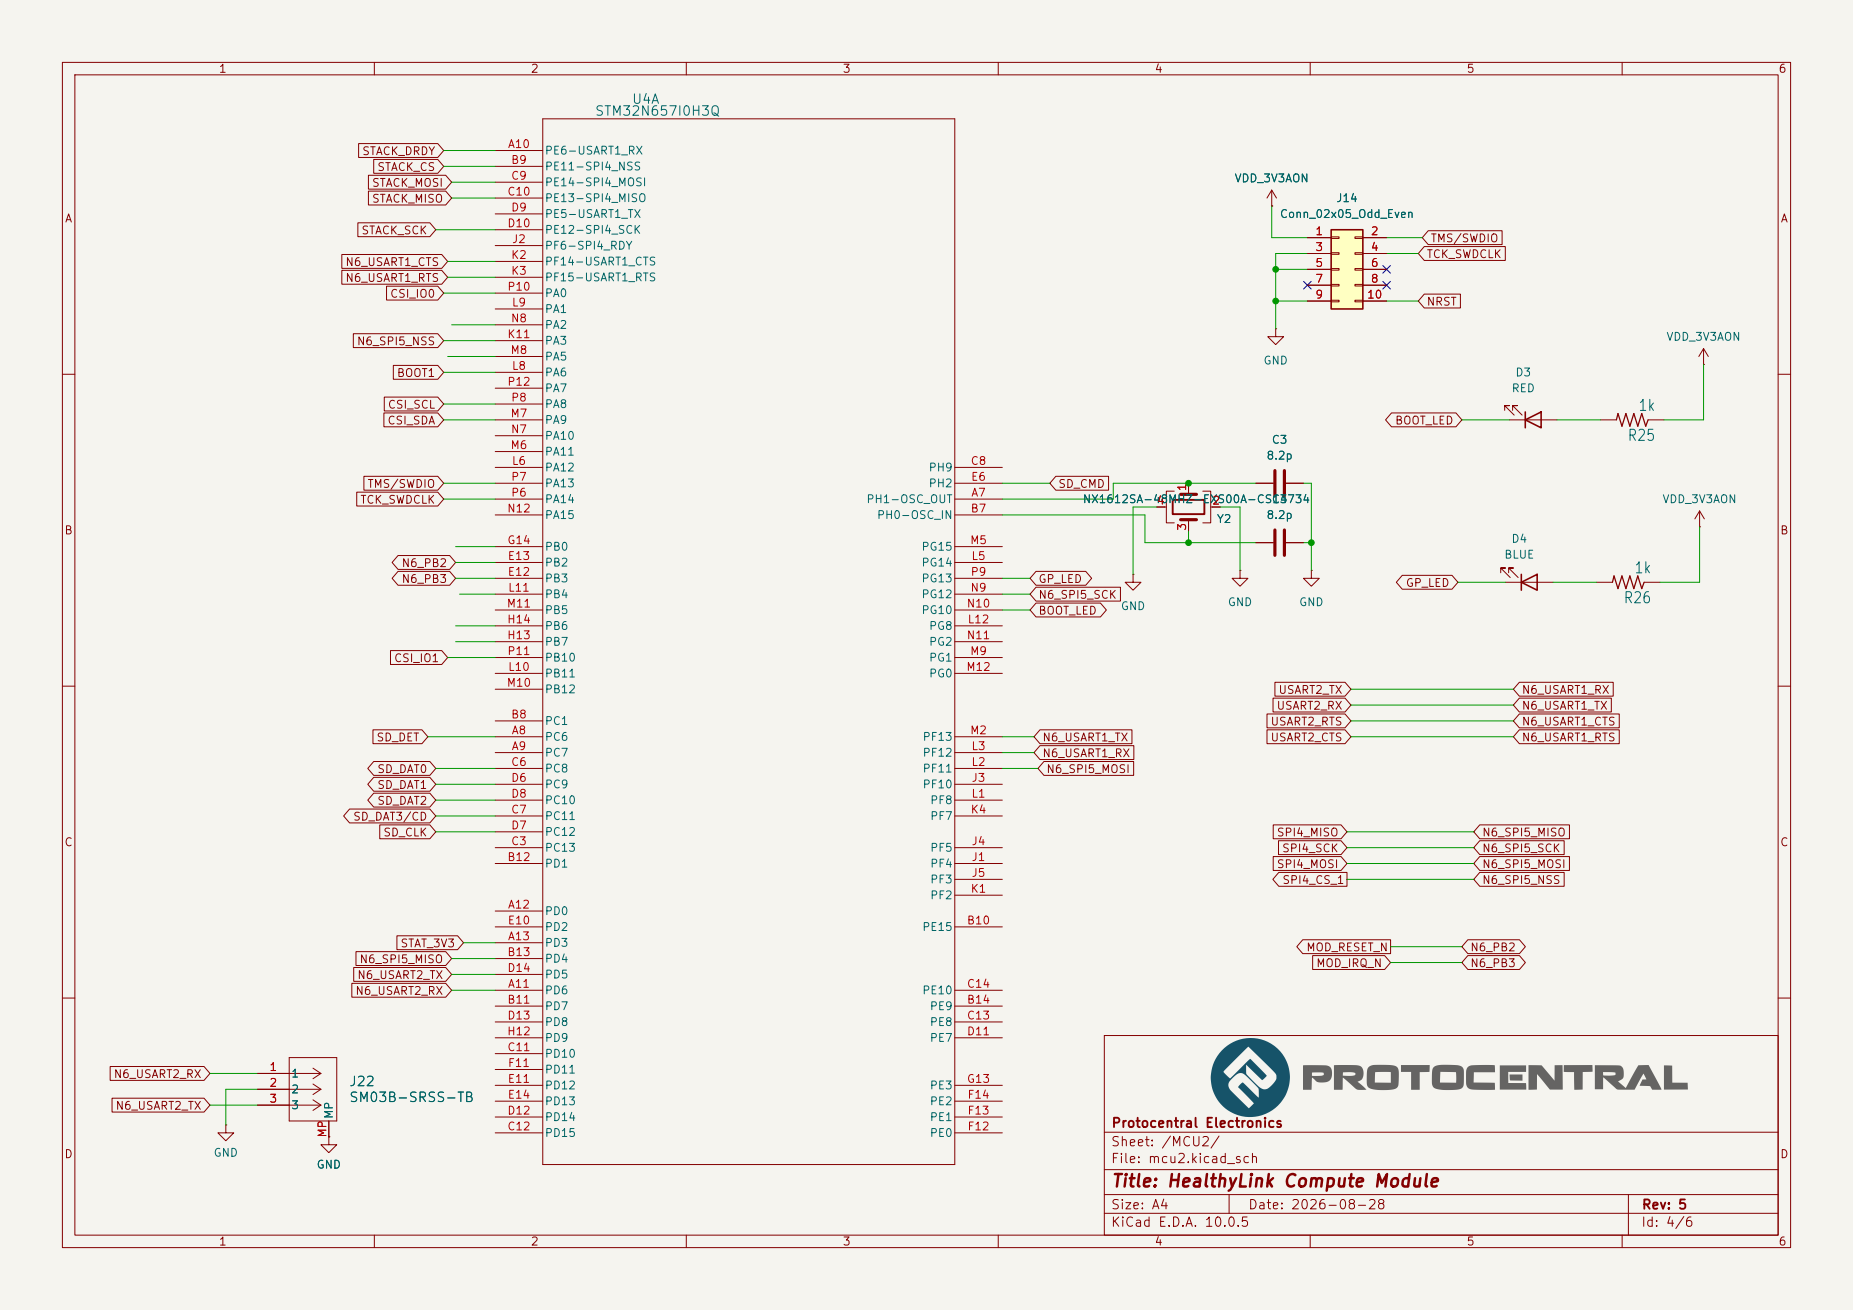
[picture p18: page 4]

Protocentral Electronics
Sheet: /MCU2/
File: mcu2.kicad_sch
Title: HealthyLink Compute Module

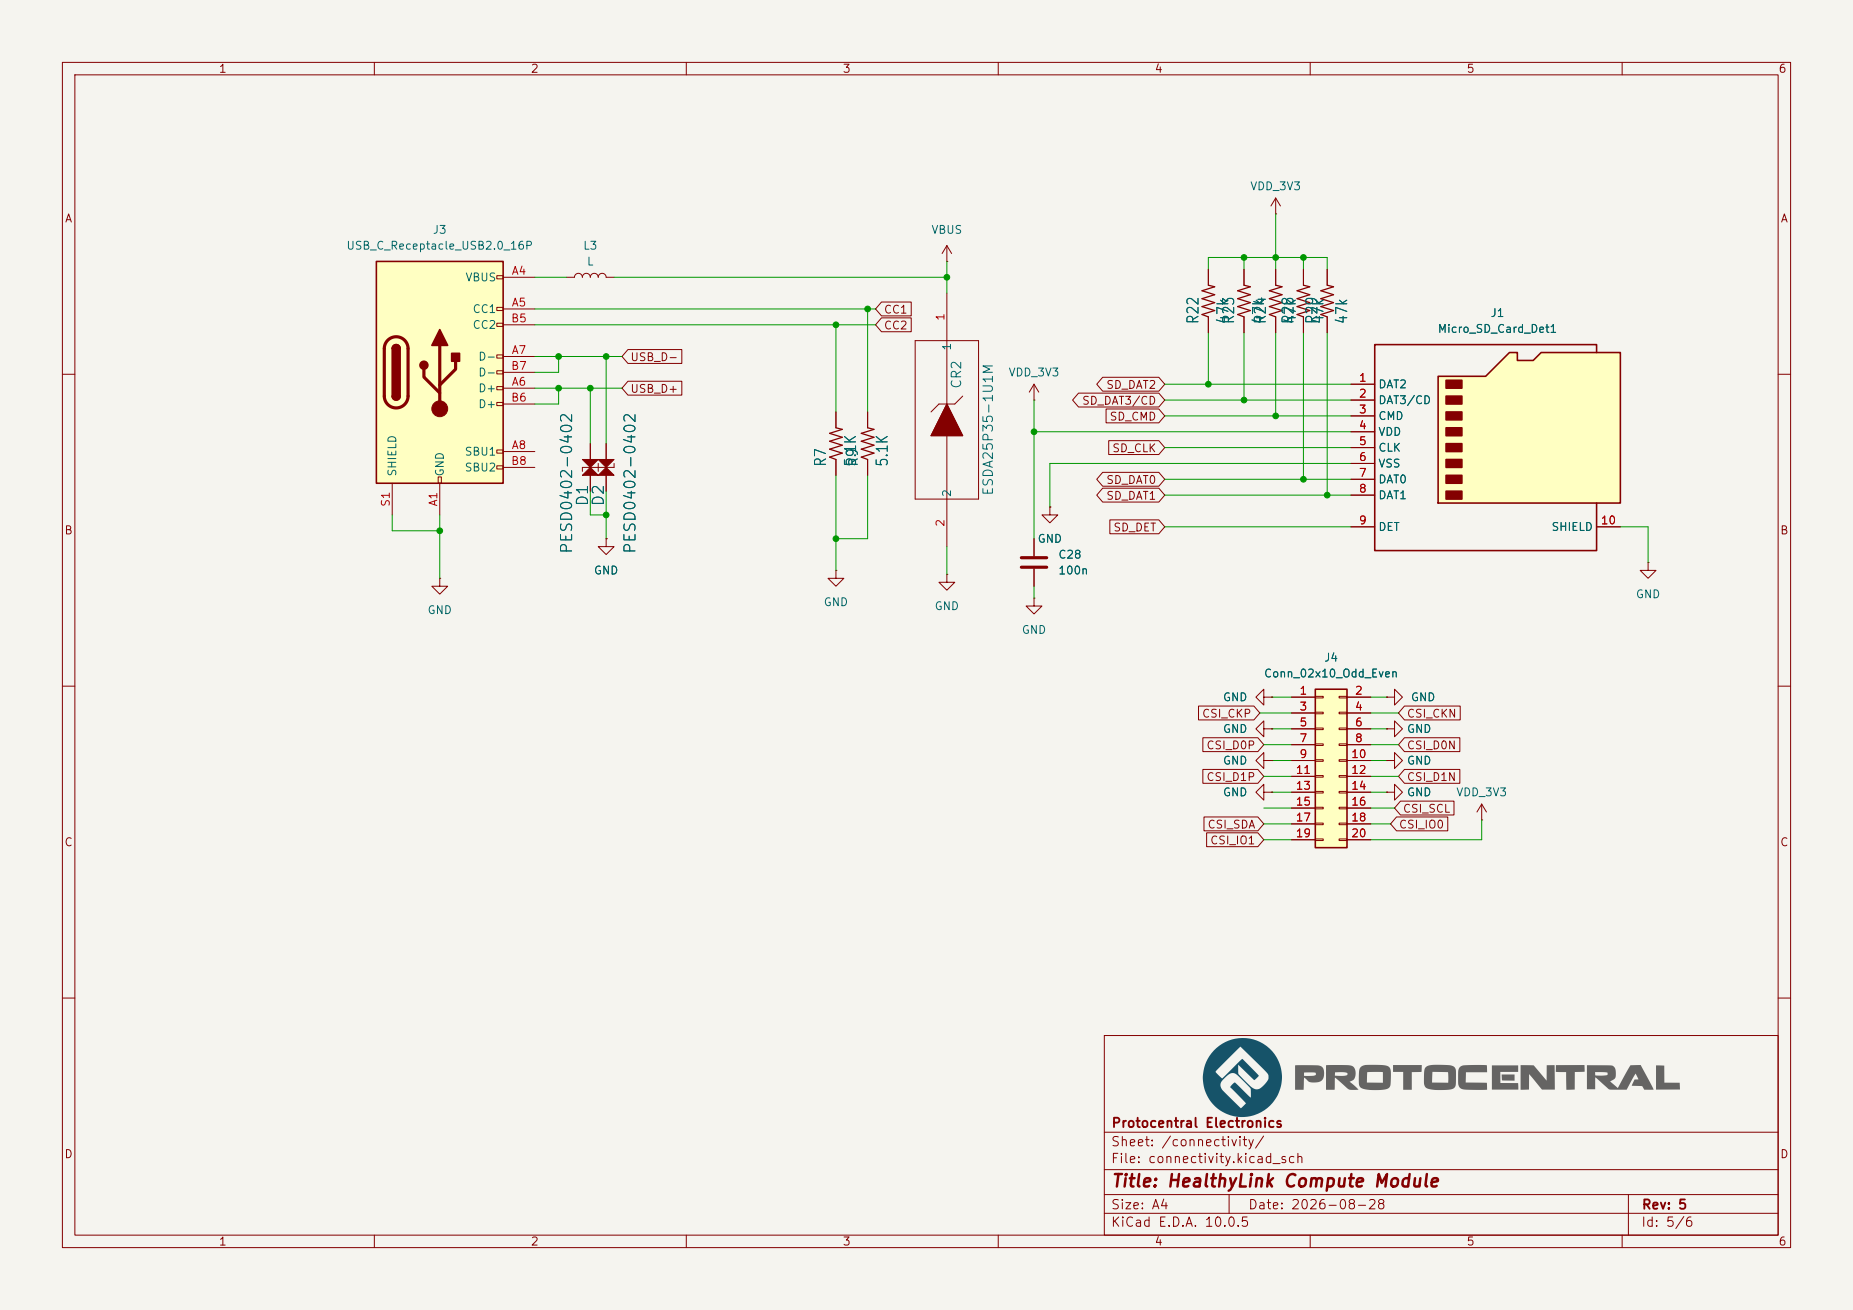
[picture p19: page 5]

Protocentral Electronics
Sheet: /connectivity/
File: connectivity.kicad_sch
Title: HealthyLink Compute Module

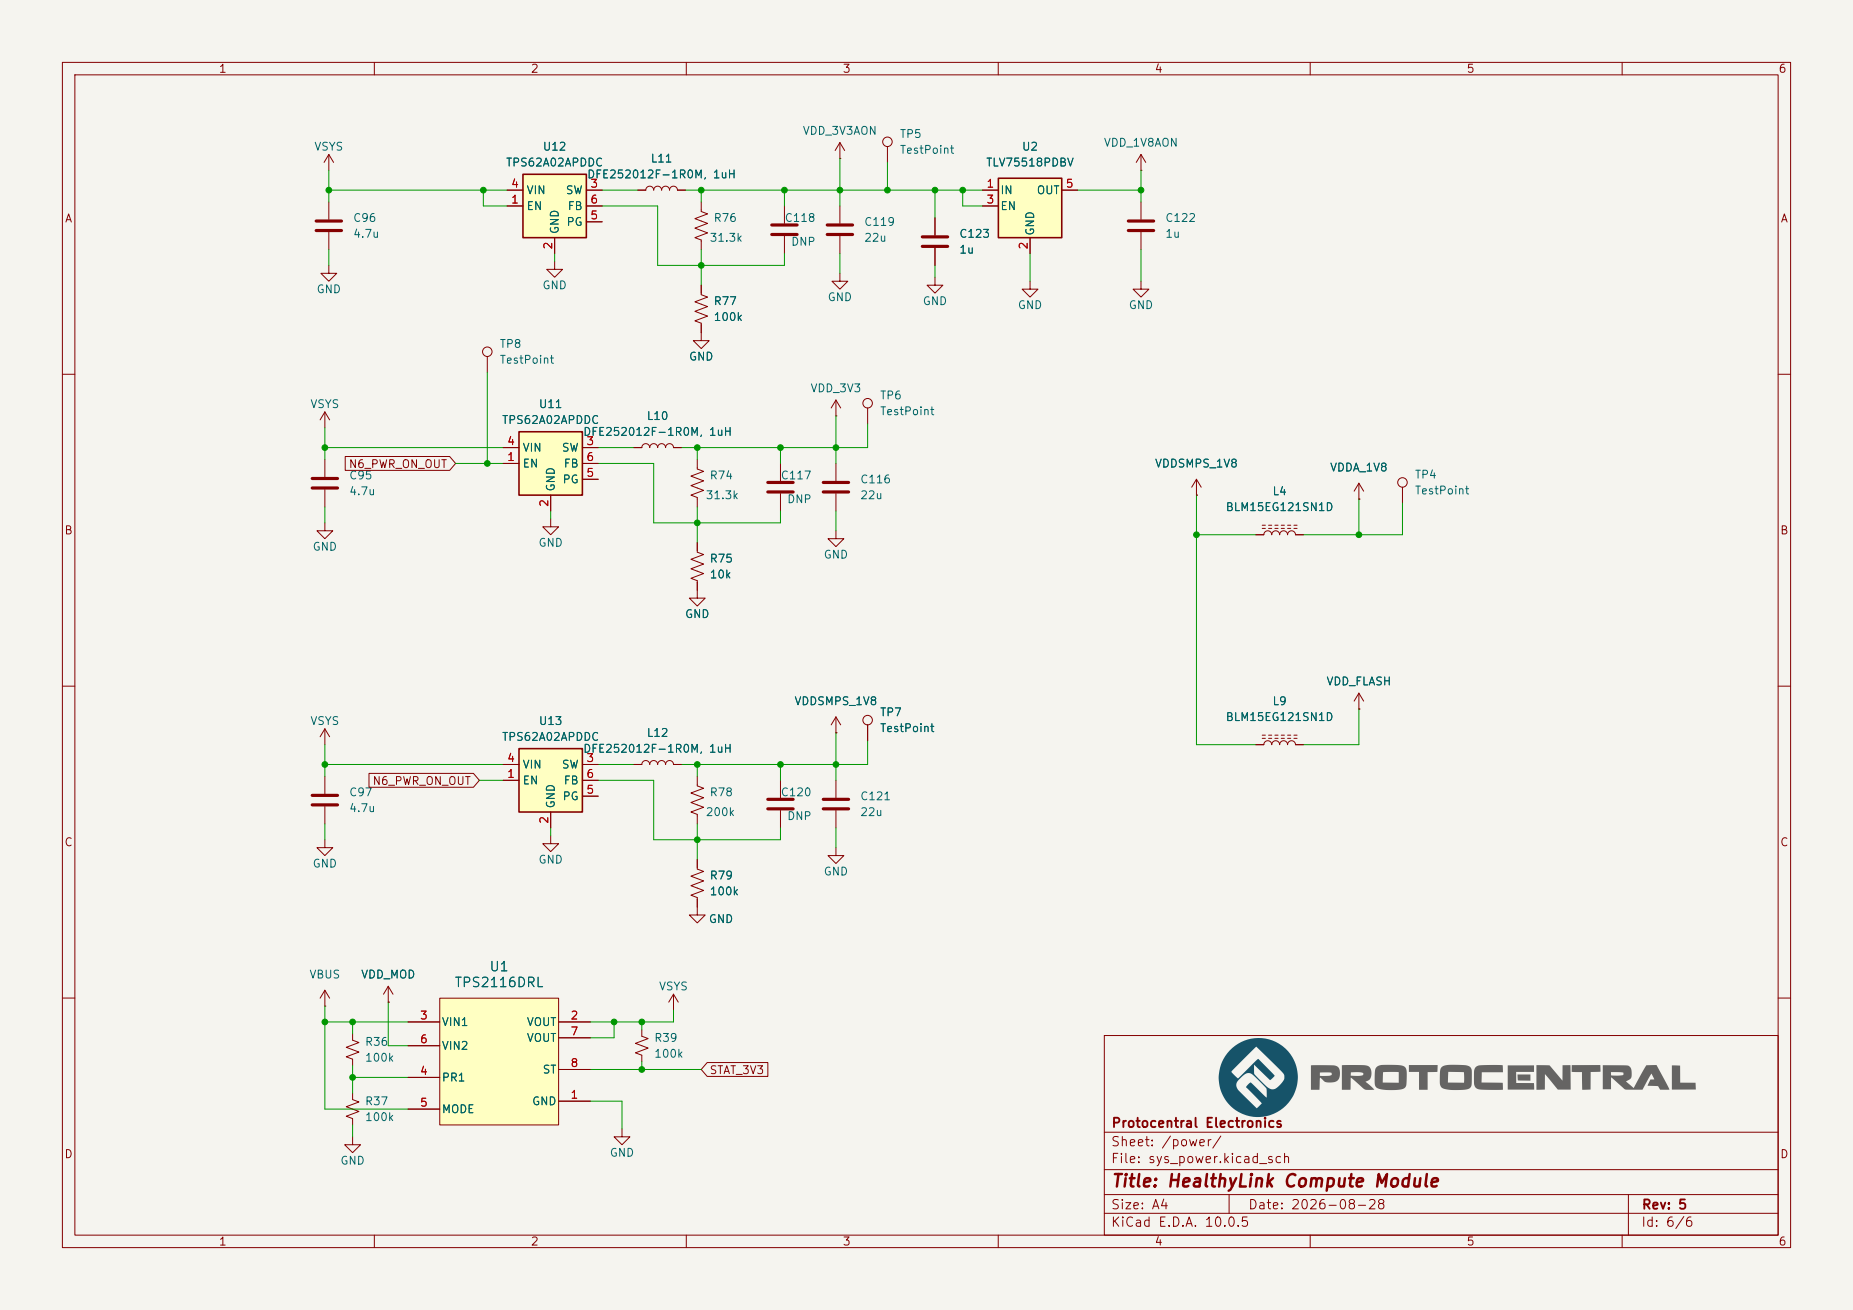
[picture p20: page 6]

Protocentral Electronics
Sheet: /power/
File: sys_power.kicad_sch
Title: HealthyLink Compute Module

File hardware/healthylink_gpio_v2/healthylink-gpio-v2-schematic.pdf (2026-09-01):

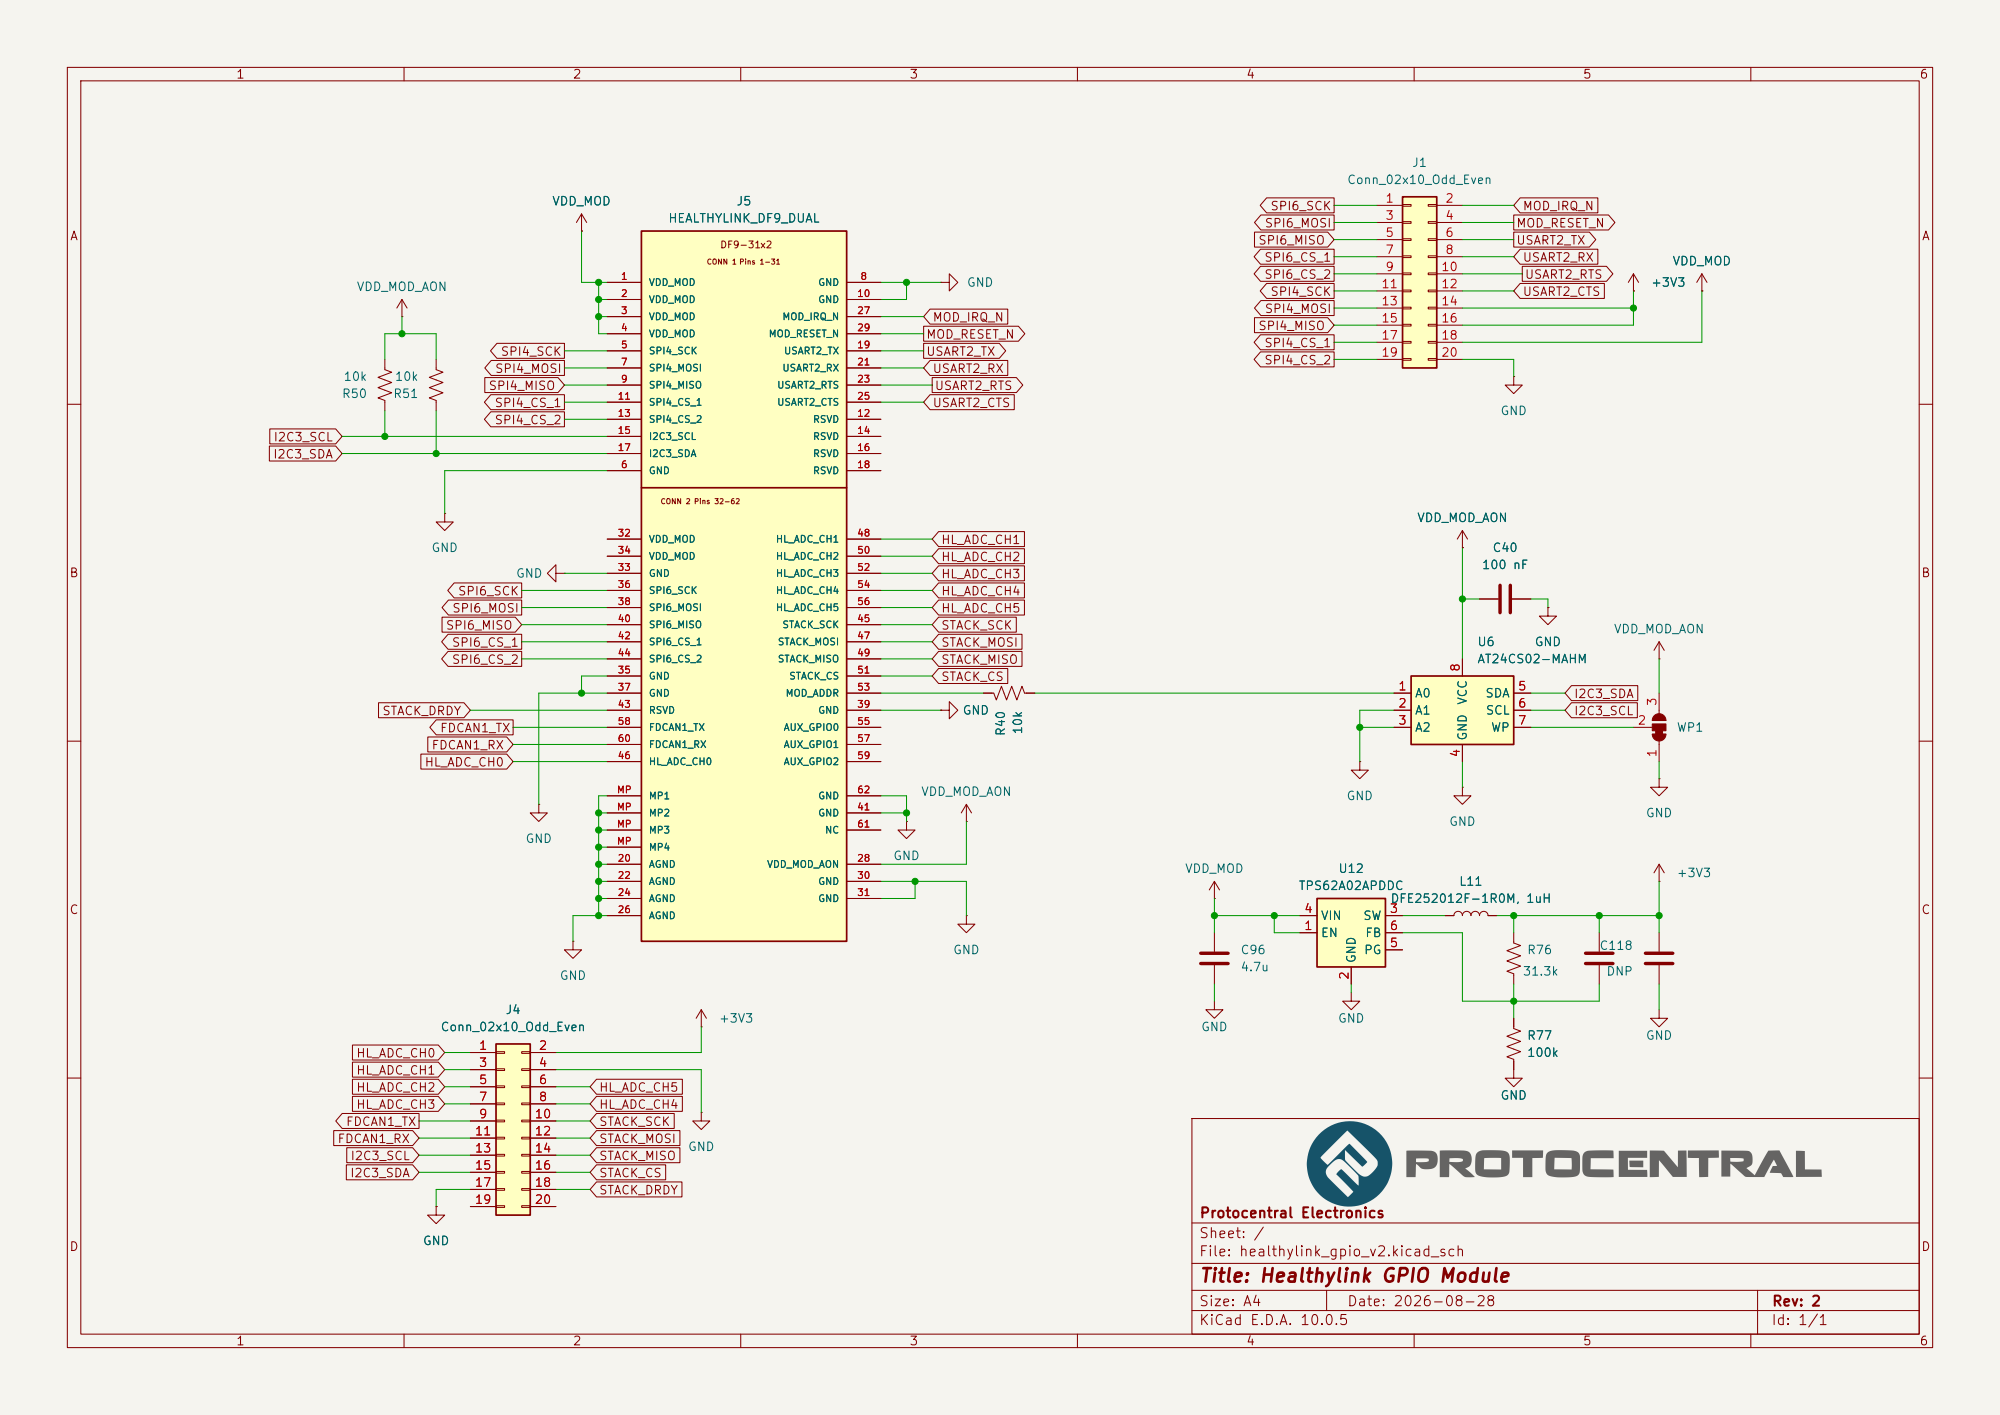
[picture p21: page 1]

Protocentral Electronics
Sheet: /
File: healthylink_gpio_v2.kicad_sch
Title: Healthylink GPIO Module

Size: A4 | Rev: 2
KiCad E.D.A. 10.0.5 | Id: 1/1

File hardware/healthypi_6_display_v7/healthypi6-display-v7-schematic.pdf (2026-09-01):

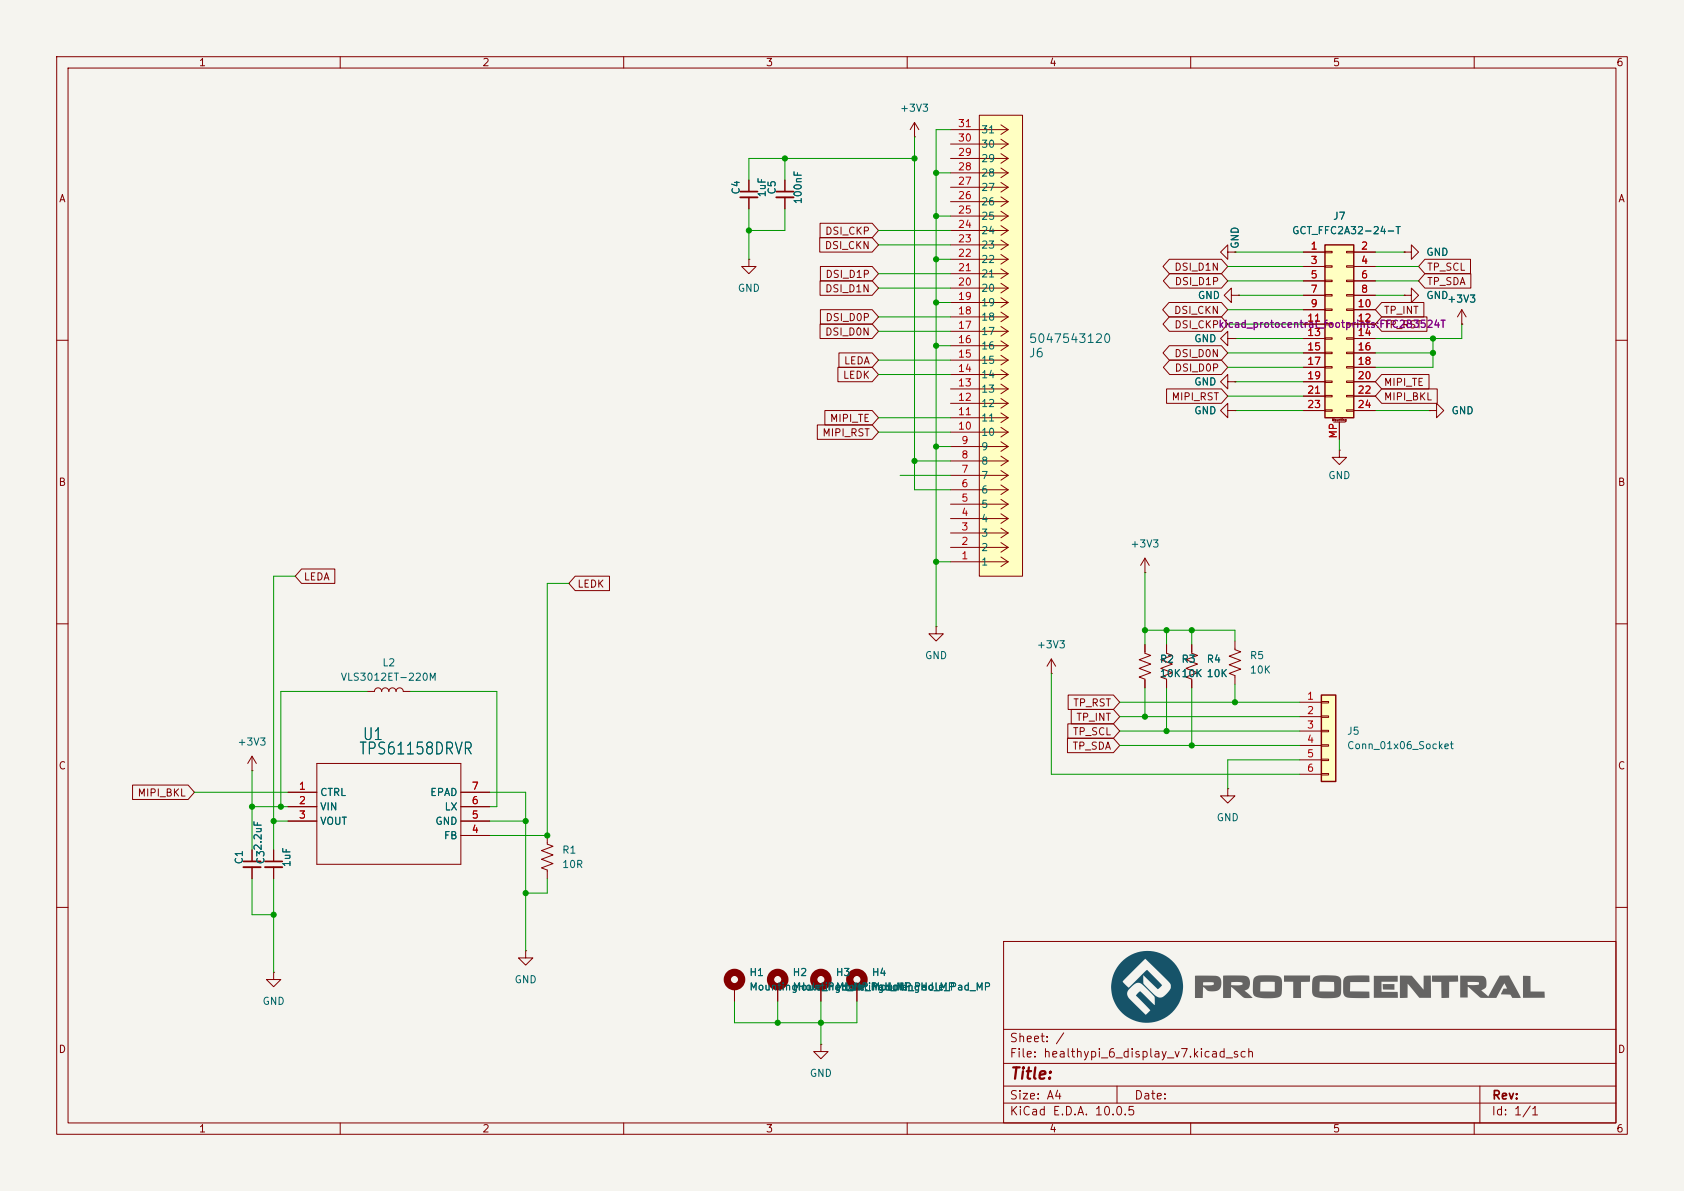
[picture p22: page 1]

Size: A4 | Rev:
KiCad E.D.A. 10.0.5 | Id: 1/1

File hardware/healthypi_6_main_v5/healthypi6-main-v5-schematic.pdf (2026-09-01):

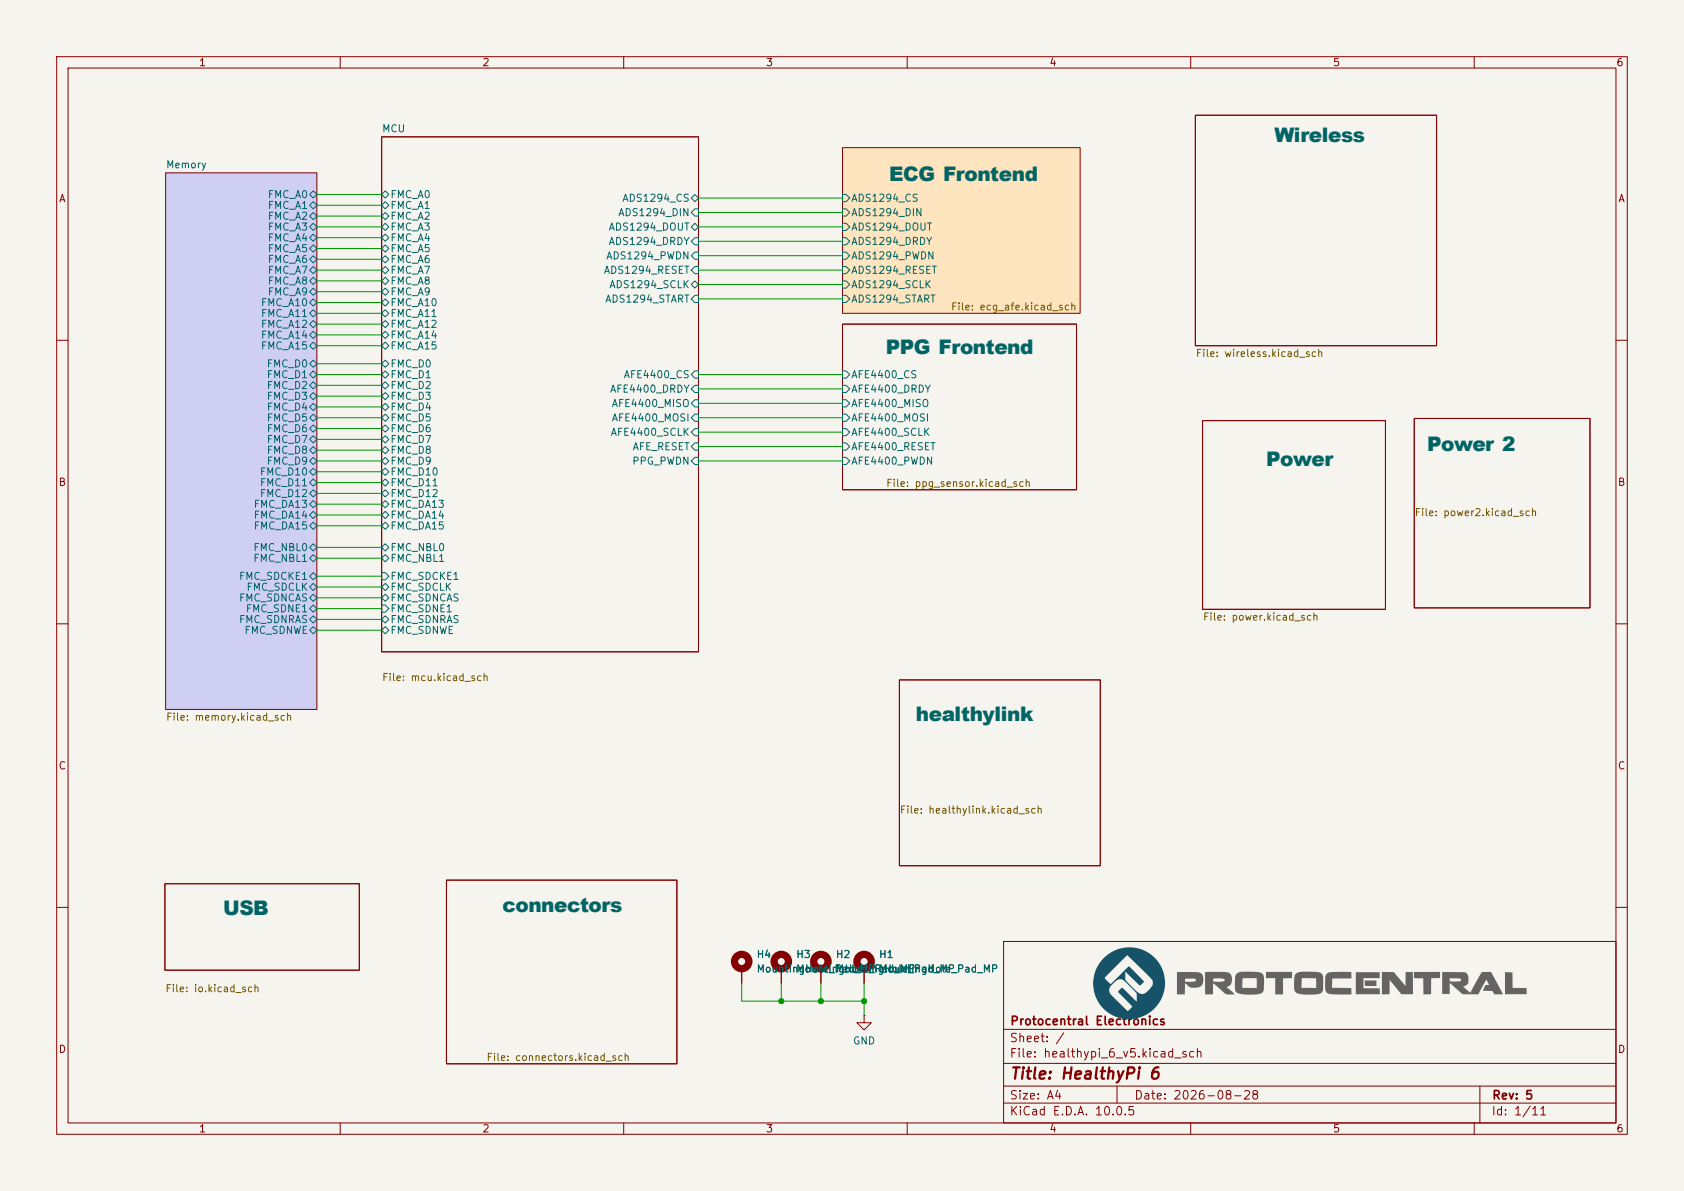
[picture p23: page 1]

Size: A4 | Rev: 5
KiCad E.D.A. 10.0.5 | Id: 1/11

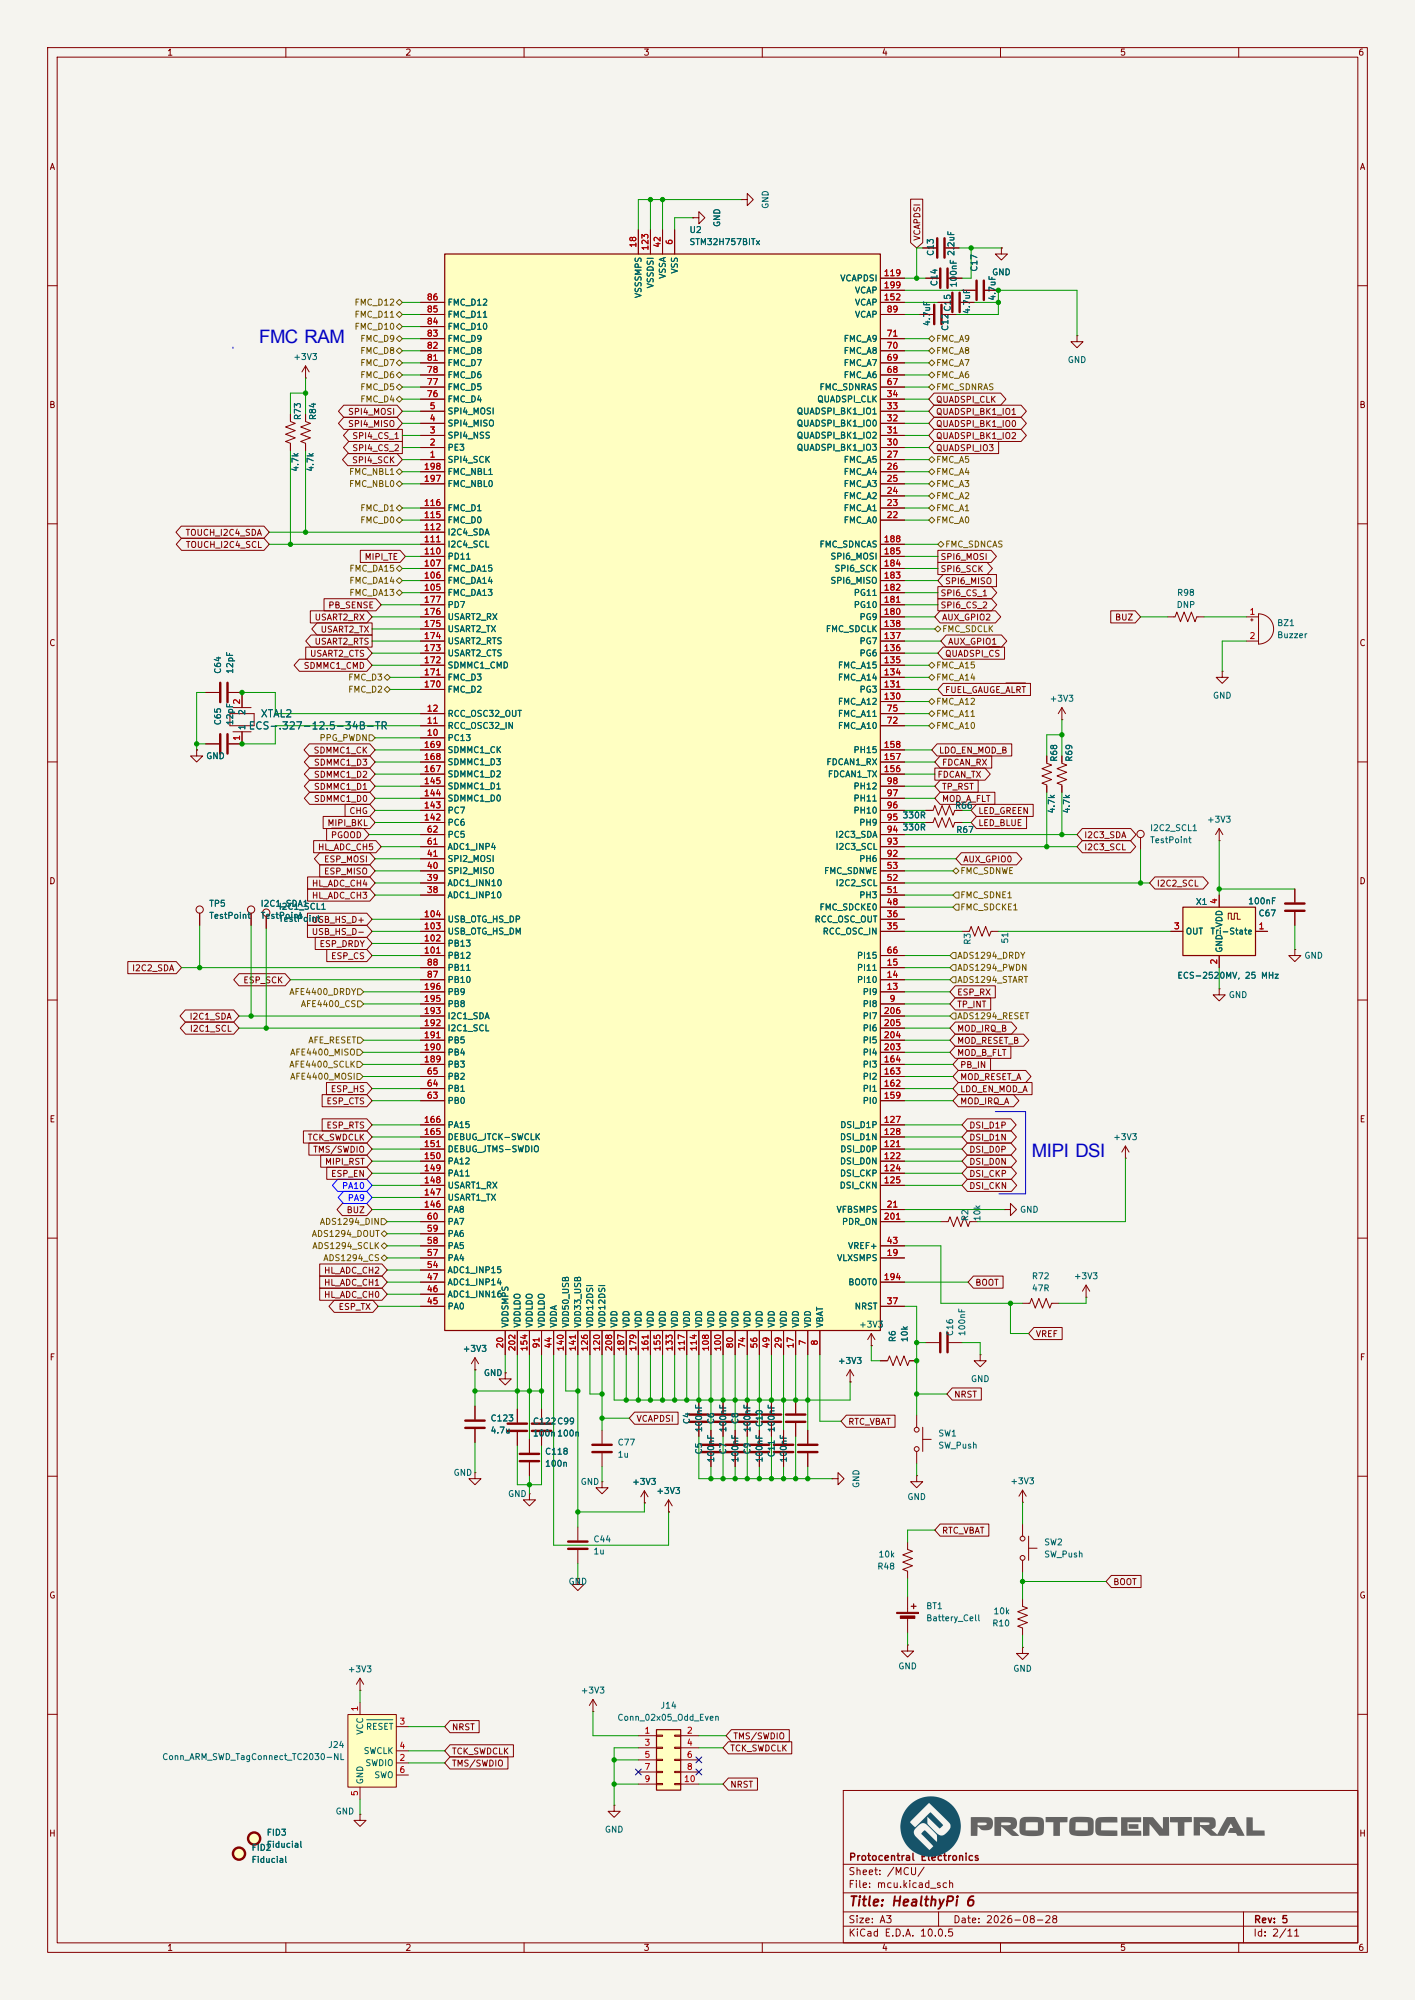
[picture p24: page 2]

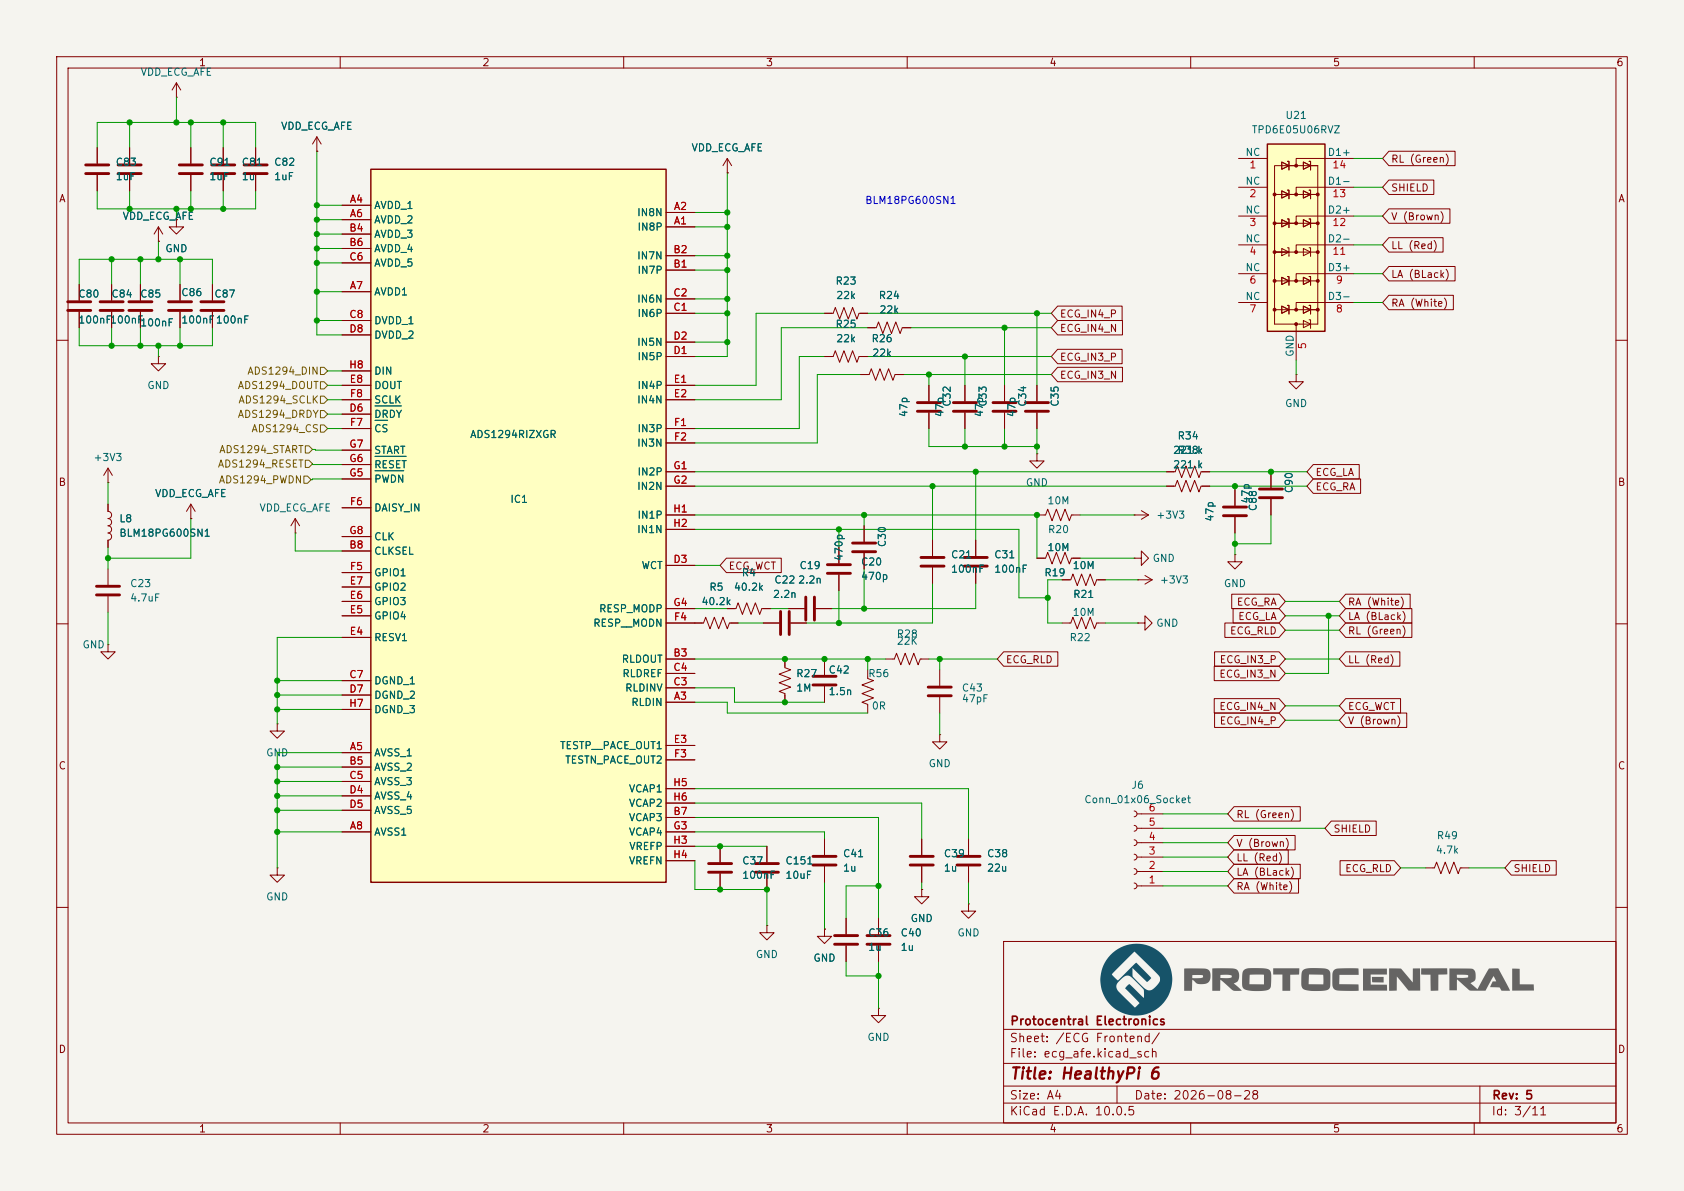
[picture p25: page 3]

V (Brown) RA (White) LL (Red) ECG_RA ECG_IN4_N

LL (Red) RL (Green) RA (White) ECG_LA ECG_RA ECG_RLD

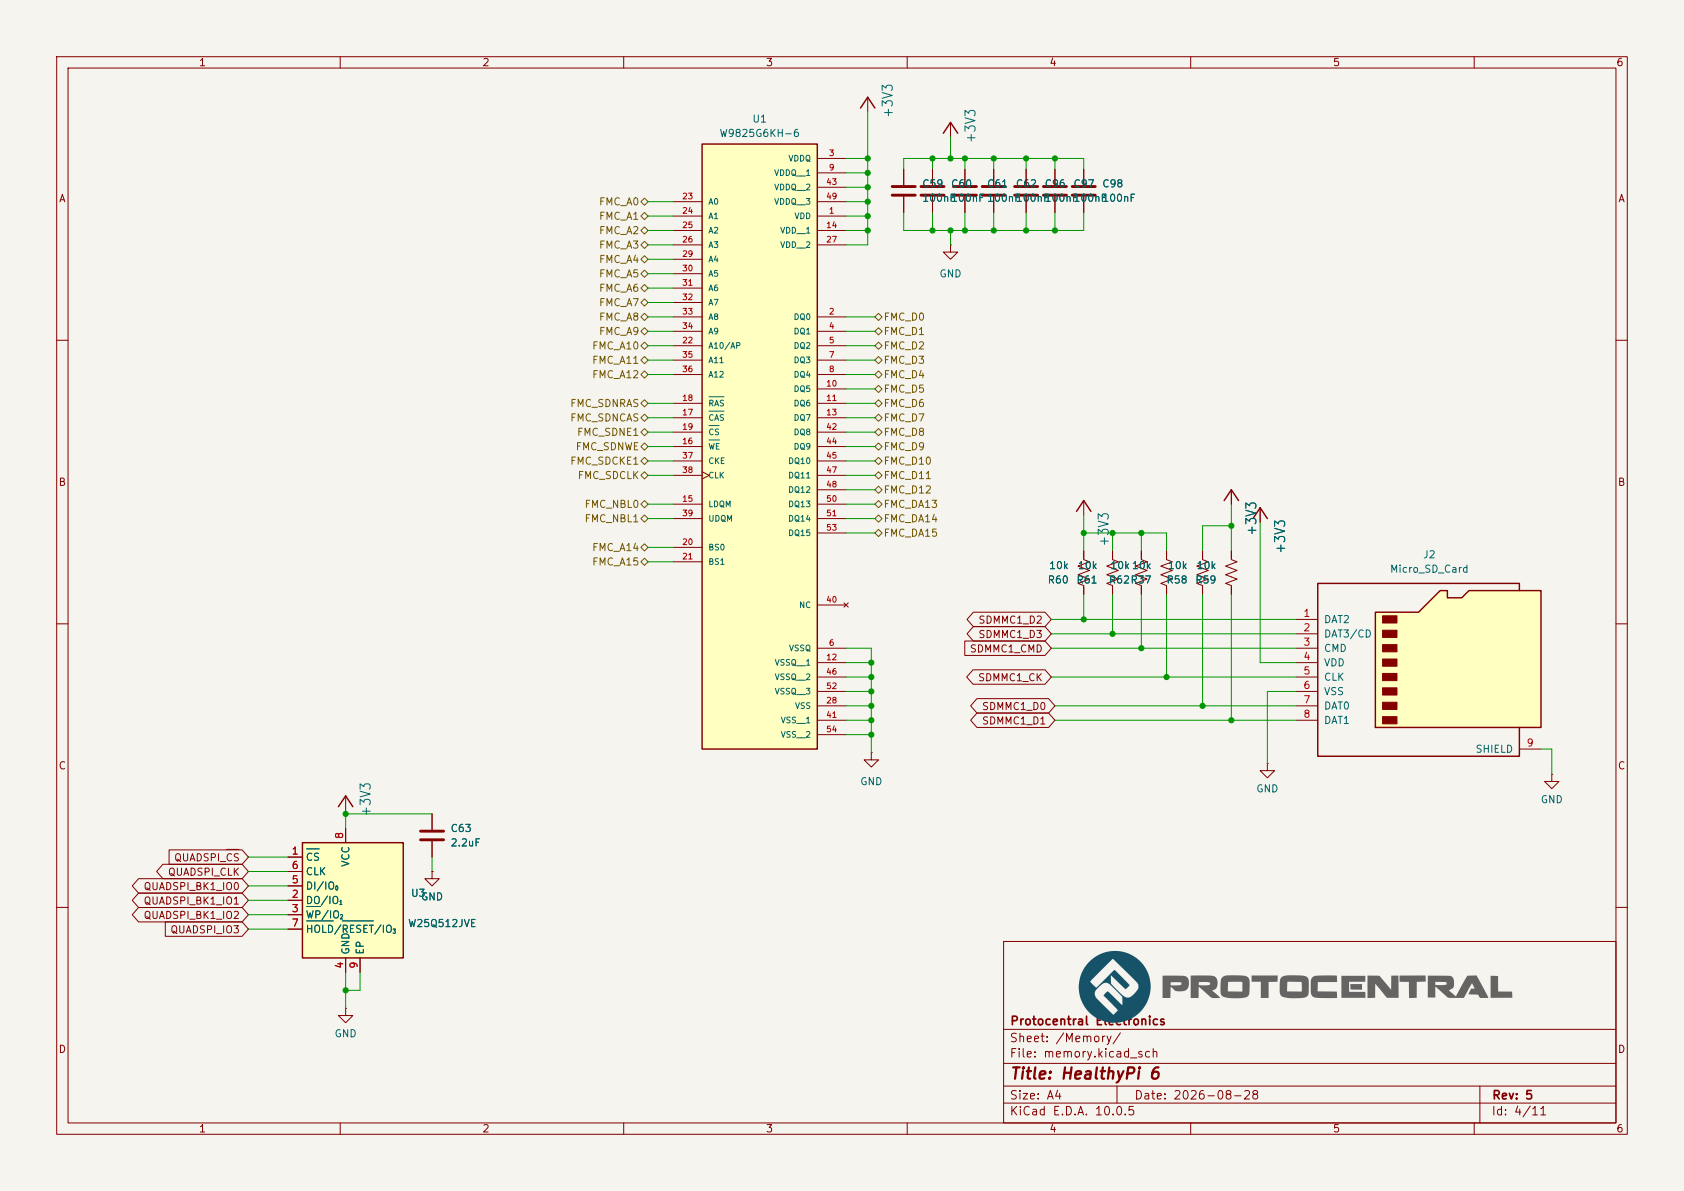
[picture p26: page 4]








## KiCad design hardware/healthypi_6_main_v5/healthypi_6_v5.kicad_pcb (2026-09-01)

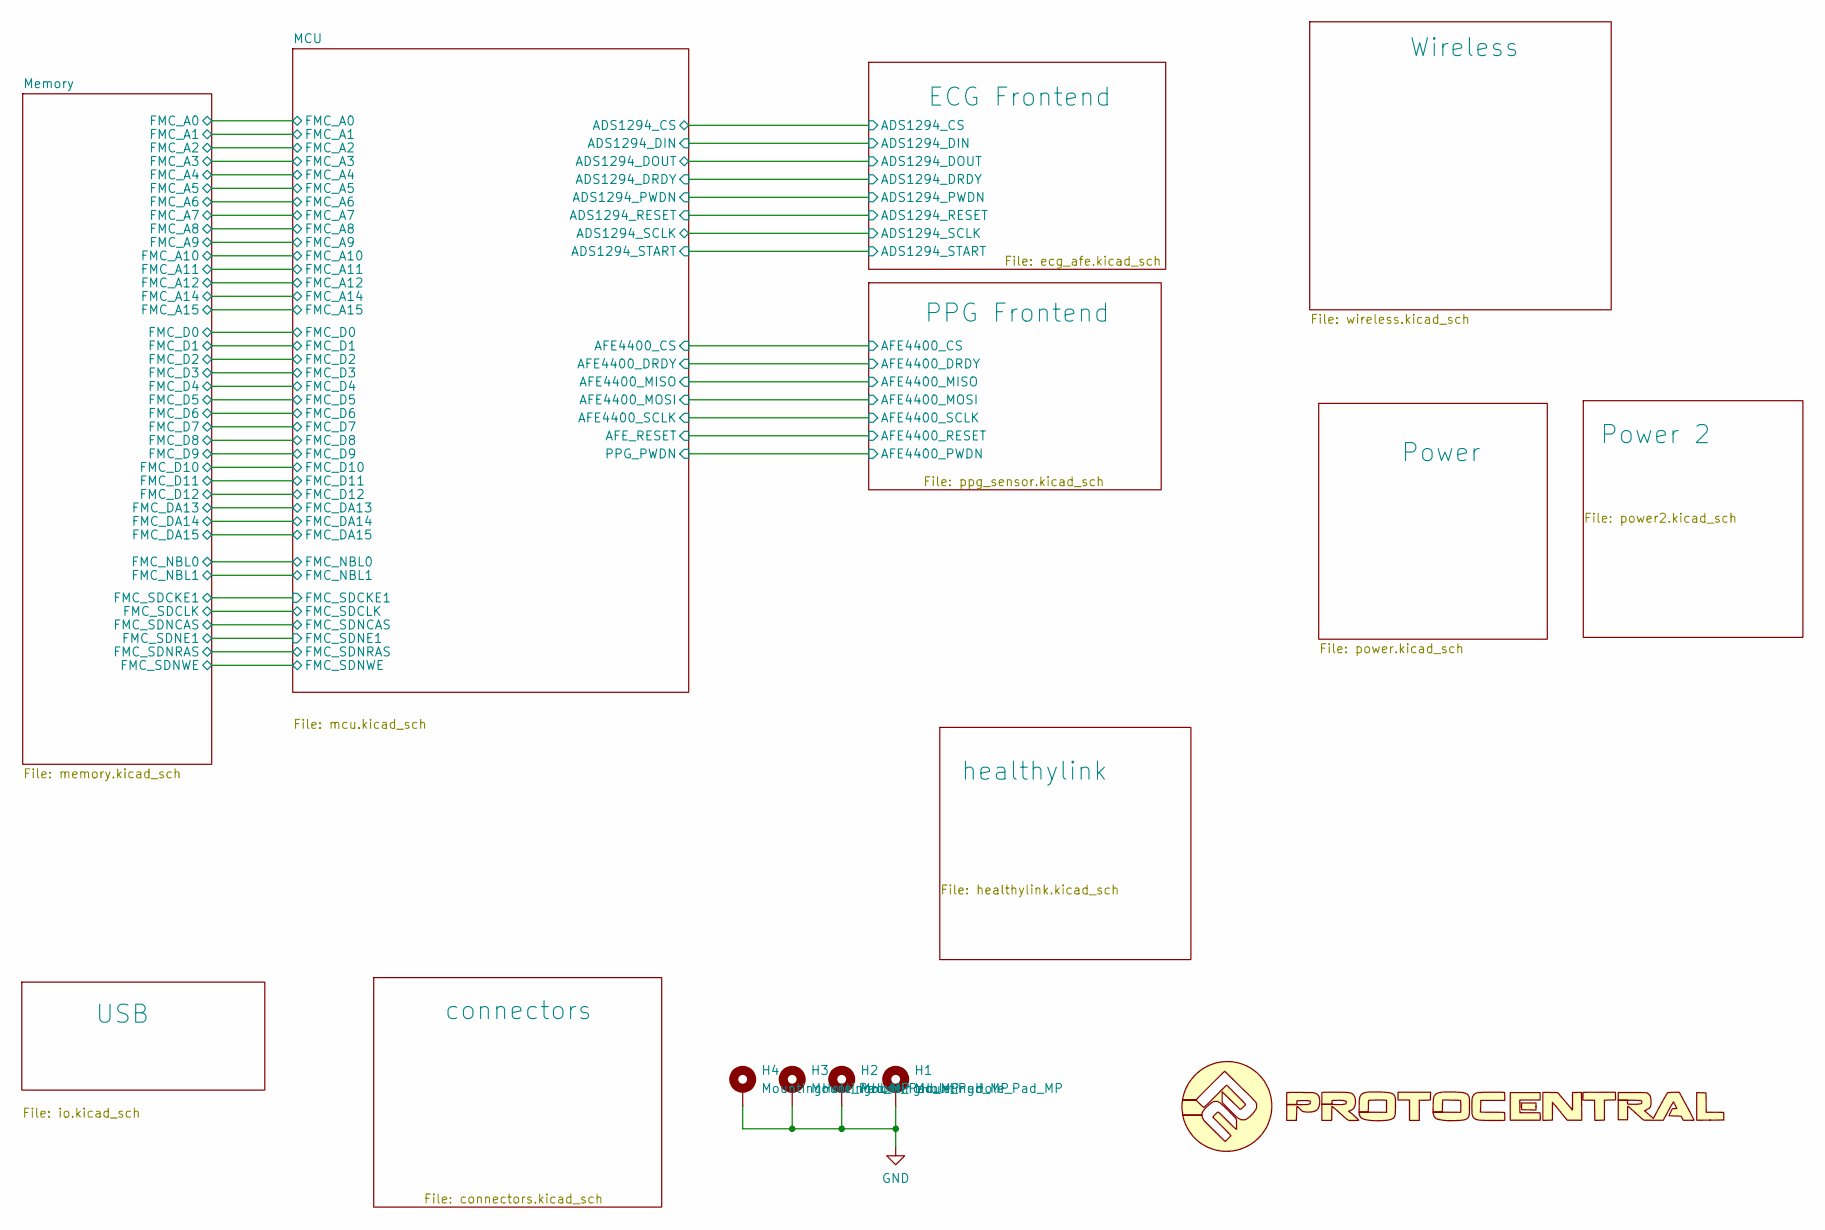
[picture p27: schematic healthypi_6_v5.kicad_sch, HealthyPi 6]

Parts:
H1, H2, H3, H4: MountingHole_Pad_MP; MountingHole_3.2mm_M3_DIN965_Pad_TopBottom
U4: LOGO

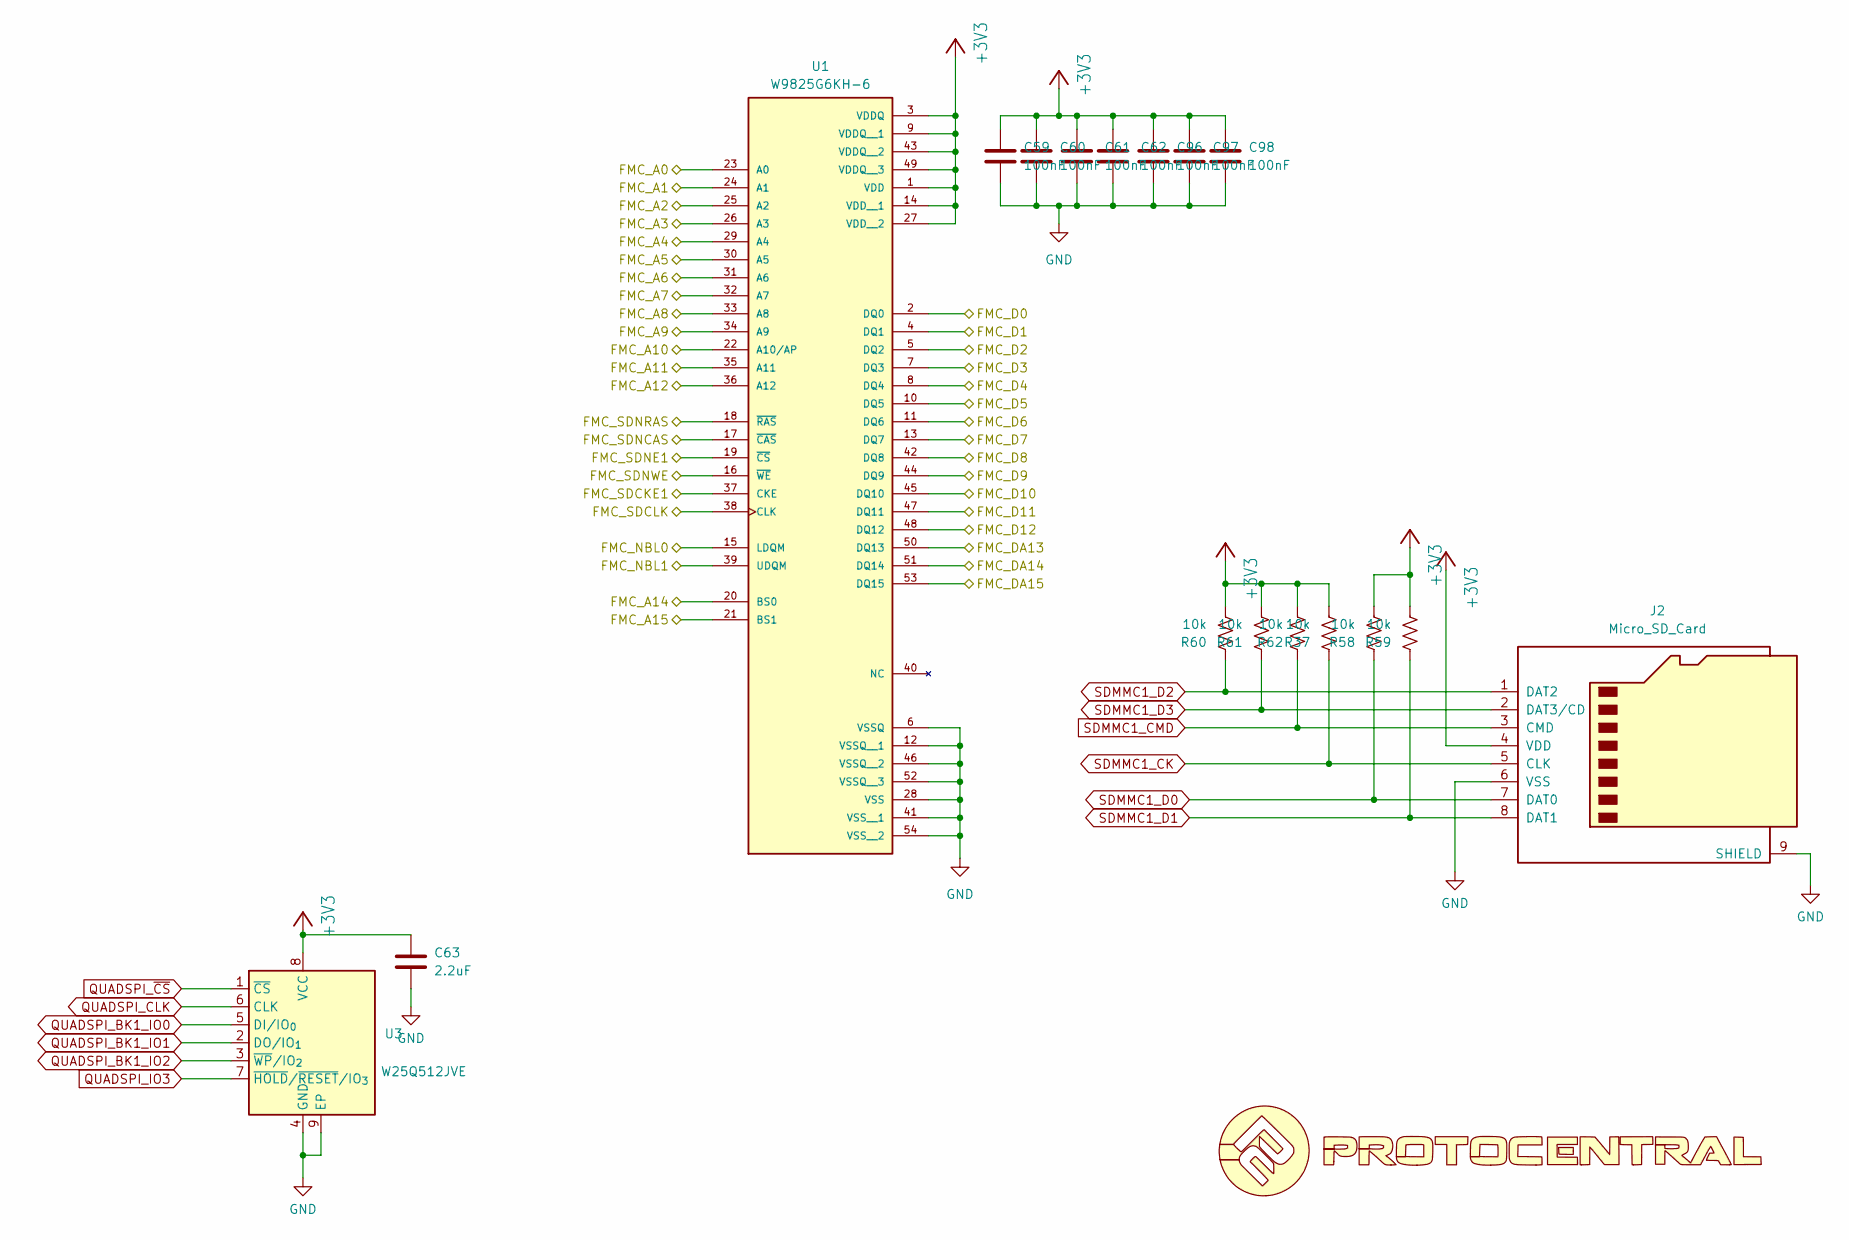
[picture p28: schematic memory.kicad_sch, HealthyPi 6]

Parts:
C59, C60, C61, C62, C96, C97, C98: 100nF; C_0402_1005Metric
C63: 2.2uF; C_0402_1005Metric
J2: Micro_SD_Card; GCT_MEM2052-00-195-00-A_REVA
R37, R58, R59, R60, R61, R62: 10k; R_0402_1005Metric
U1: W9825G6KH-6; SOP80P1176X120-54N; PARTREV A05
U3: W25Q512JVE; WSON-8-1EP_8x6mm_P1.27mm_EP3.4x4.3mm
U16: LOGO

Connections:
+3V3: C59.2, C60.2, C61.2, C62.2, C63.2, C96.2, C97.2, C98.2, J2.4 (VDD), R37.2, R58.2, R59.2, R60.2, R61.2, R62.2, U1.1 (VDD), U1.3 (VDDQ), U1.9 (VDDQ__1), U1.14 (VDD__1), U1.27 (VDD__2), U1.43 (VDDQ__2), U1.49 (VDDQ__3), U3.8 (VCC); also elsewhere on the board
/MCU/FMC_A0: U1.23 (A0); also elsewhere on the board
/MCU/FMC_A1: U1.24 (A1); also elsewhere on the board
/MCU/FMC_A2: U1.25 (A2); also elsewhere on the board
/MCU/FMC_A3: U1.26 (A3); also elsewhere on the board
/MCU/FMC_A4: U1.29 (A4); also elsewhere on the board
/MCU/FMC_A5: U1.30 (A5); also elsewhere on the board
/MCU/FMC_A6: U1.31 (A6); also elsewhere on the board
/MCU/FMC_A7: U1.32 (A7); also elsewhere on the board
/MCU/FMC_A8: U1.33 (A8); also elsewhere on the board
/MCU/FMC_A9: U1.34 (A9); also elsewhere on the board
/MCU/FMC_A10: U1.22 (A10/AP); also elsewhere on the board
/MCU/FMC_A11: U1.35 (A11); also elsewhere on the board
/MCU/FMC_A12: U1.36 (A12); also elsewhere on the board
/MCU/FMC_A14: U1.20 (BS0); also elsewhere on the board
/MCU/FMC_A15: U1.21 (BS1); also elsewhere on the board
/MCU/FMC_D0: U1.2 (DQ0); also elsewhere on the board
/MCU/FMC_D1: U1.4 (DQ1); also elsewhere on the board
/MCU/FMC_D2: U1.5 (DQ2); also elsewhere on the board
/MCU/FMC_D3: U1.7 (DQ3); also elsewhere on the board
/MCU/FMC_D4: U1.8 (DQ4); also elsewhere on the board
/MCU/FMC_D5: U1.10 (DQ5); also elsewhere on the board
/MCU/FMC_D6: U1.11 (DQ6); also elsewhere on the board
/MCU/FMC_D7: U1.13 (DQ7); also elsewhere on the board
/MCU/FMC_D8: U1.42 (DQ8); also elsewhere on the board
/MCU/FMC_D9: U1.44 (DQ9); also elsewhere on the board
/MCU/FMC_D10: U1.45 (DQ10); also elsewhere on the board
/MCU/FMC_D11: U1.47 (DQ11); also elsewhere on the board
/MCU/FMC_D12: U1.48 (DQ12); also elsewhere on the board
/MCU/FMC_DA13: U1.50 (DQ13); also elsewhere on the board
/MCU/FMC_DA14: U1.51 (DQ14); also elsewhere on the board
/MCU/FMC_DA15: U1.53 (DQ15); also elsewhere on the board
/MCU/FMC_NBL0: U1.15 (LDQM); also elsewhere on the board
/MCU/FMC_NBL1: U1.39 (UDQM); also elsewhere on the board
/MCU/FMC_SDCKE1: U1.37 (CKE); also elsewhere on the board
/MCU/FMC_SDCLK: U1.38 (CLK); also elsewhere on the board
/MCU/FMC_SDNCAS: U1.17 (~CAS); also elsewhere on the board
/MCU/FMC_SDNE1: U1.19 (~CS); also elsewhere on the board
/MCU/FMC_SDNRAS: U1.18 (~RAS); also elsewhere on the board
/MCU/FMC_SDNWE: U1.16 (~WE); also elsewhere on the board
GND: C59.1, C60.1, C61.1, C62.1, C63.1, C96.1, C97.1, C98.1, J2.6 (VSS), J2.9 (SHIELD), U1.6 (VSSQ), U1.12 (VSSQ__1), U1.28 (VSS), U1.41 (VSS__1), U1.46 (VSSQ__2), U1.52 (VSSQ__3), U1.54 (VSS__2), U3.4 (GND), U3.9 (EP); also elsewhere on the board
QUADSPI_BK1_IO0: U3.5 (DI/IO_{0}); also elsewhere on the board
QUADSPI_BK1_IO1: U3.2 (DO/IO_{1}); also elsewhere on the board
QUADSPI_BK1_IO2: U3.3 (~WP/IO_{2}); also elsewhere on the board
QUADSPI_CLK: U3.6 (CLK); also elsewhere on the board
QUADSPI_IO3: U3.7 (~HOLD/~RESET/IO_{3}); also elsewhere on the board
QUADSPI_~CS: U3.1 (~CS); also elsewhere on the board
SDMMC1_CK: J2.5 (CLK), R37.1; also elsewhere on the board
SDMMC1_CMD: J2.3 (CMD), R62.1; also elsewhere on the board
SDMMC1_D0: J2.7 (DAT0), R58.1; also elsewhere on the board
SDMMC1_D1: J2.8 (DAT1), R59.1; also elsewhere on the board
SDMMC1_D2: J2.1 (DAT2), R60.1; also elsewhere on the board
SDMMC1_D3: J2.2 (DAT3/CD), R61.1; also elsewhere on the board

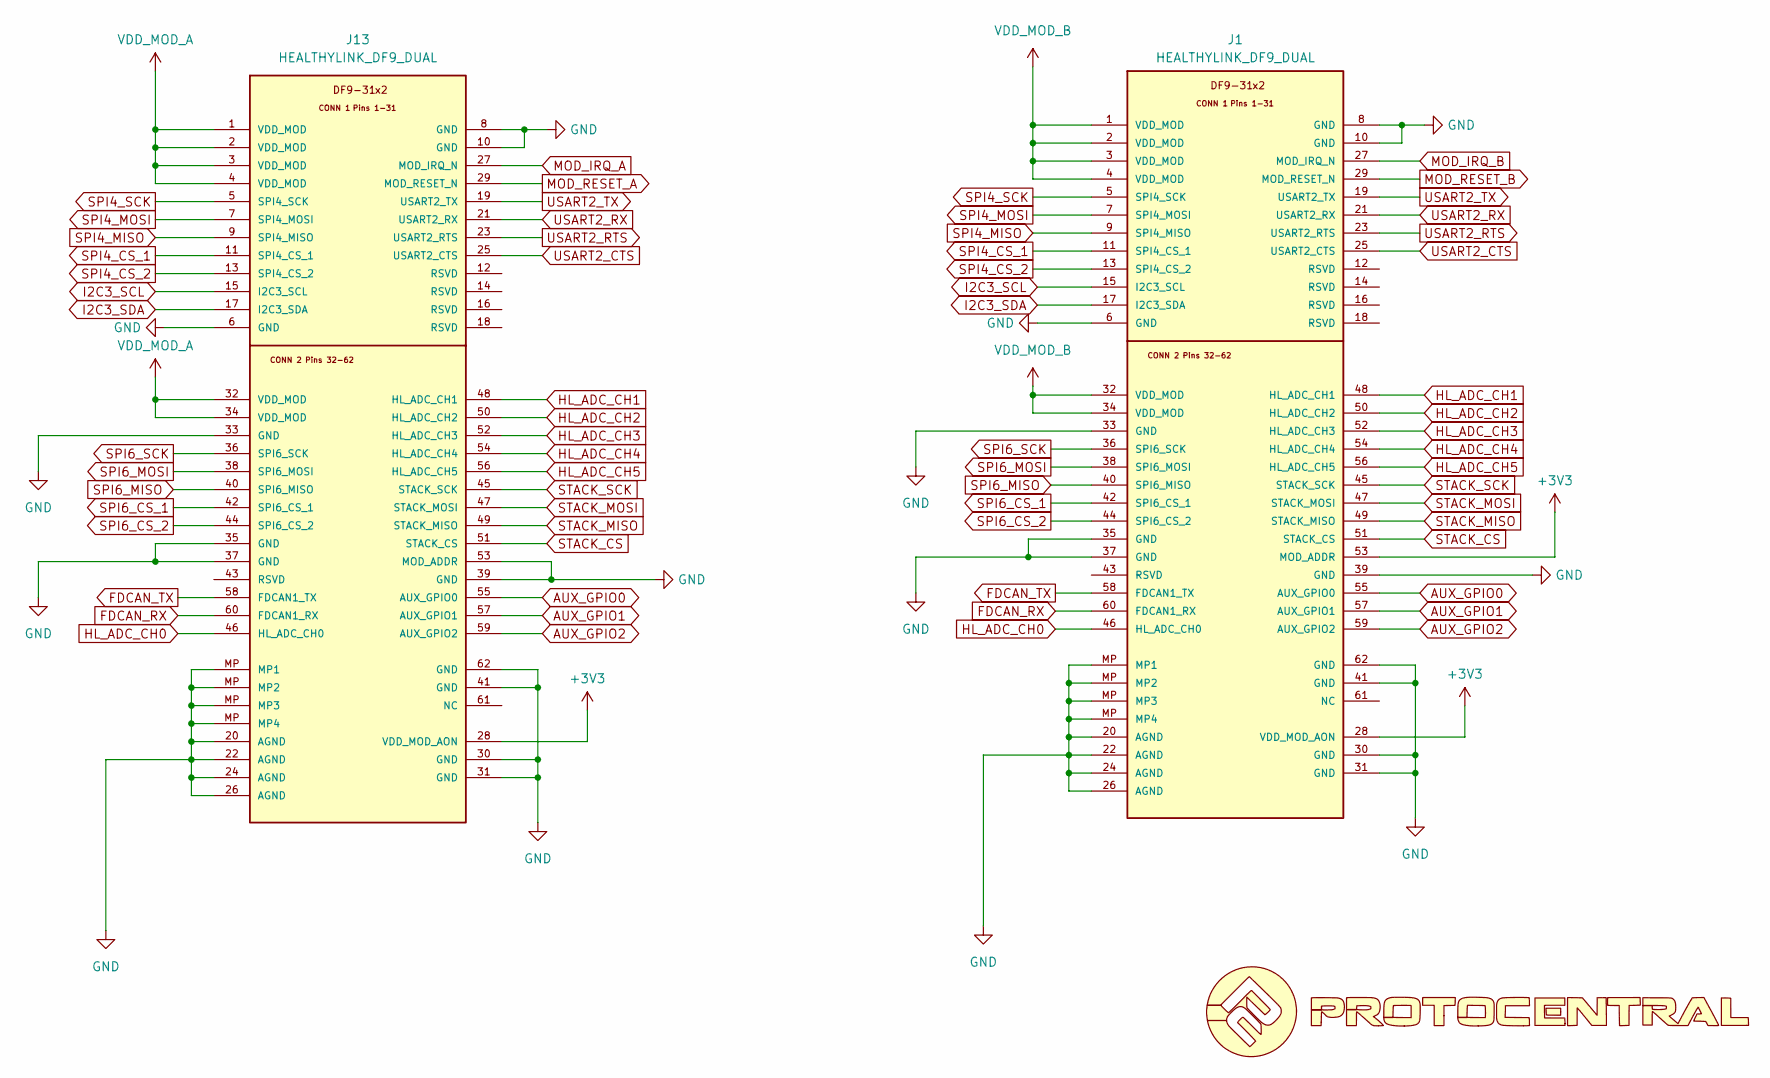
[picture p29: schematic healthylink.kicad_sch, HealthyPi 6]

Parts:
J1, J13: HEALTHYLINK_DF9_DUAL; healthylink_df9_module_slot
U23: LOGO

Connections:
+3V3: J1.28 (VDD_MOD_AON), J1.53 (MOD_ADDR), J13.28 (VDD_MOD_AON); also elsewhere on the board
AUX_GPIO0: J1.55 (AUX_GPIO0), J13.55 (AUX_GPIO0); also elsewhere on the board
AUX_GPIO1: J1.57 (AUX_GPIO1), J13.57 (AUX_GPIO1); also elsewhere on the board
AUX_GPIO2: J1.59 (AUX_GPIO2), J13.59 (AUX_GPIO2); also elsewhere on the board
FDCAN_RX: J1.60 (FDCAN1_RX), J13.60 (FDCAN1_RX); also elsewhere on the board
FDCAN_TX: J1.58 (FDCAN1_TX), J13.58 (FDCAN1_TX); also elsewhere on the board
GND: J1.6 (GND), J1.8 (GND), J1.10 (GND), J1.20 (AGND), J1.22 (AGND), J1.24 (AGND), J1.26 (AGND), J1.30 (GND), J1.31 (GND), J1.33 (GND), J1.35 (GND), J1.37 (GND), J1.39 (GND), J1.41 (GND), J1.62 (GND), J1.MP (MP4), J13.6 (GND), J13.8 (GND), J13.10 (GND), J13.20 (AGND), J13.22 (AGND), J13.24 (AGND), J13.26 (AGND), J13.30 (GND), J13.31 (GND), J13.33 (GND), J13.35 (GND), J13.37 (GND), J13.39 (GND), J13.41 (GND), J13.53 (MOD_ADDR), J13.62 (GND), J13.MP (MP1); also elsewhere on the board
HL_ADC_CH0: J1.46 (HL_ADC_CH0), J13.46 (HL_ADC_CH0); also elsewhere on the board
HL_ADC_CH1: J1.48 (HL_ADC_CH1), J13.48 (HL_ADC_CH1); also elsewhere on the board
HL_ADC_CH2: J1.50 (HL_ADC_CH2), J13.50 (HL_ADC_CH2); also elsewhere on the board
HL_ADC_CH3: J1.52 (HL_ADC_CH3), J13.52 (HL_ADC_CH3); also elsewhere on the board
HL_ADC_CH4: J1.54 (HL_ADC_CH4), J13.54 (HL_ADC_CH4); also elsewhere on the board
HL_ADC_CH5: J1.56 (HL_ADC_CH5), J13.56 (HL_ADC_CH5); also elsewhere on the board
I2C3_SCL: J1.15 (I2C3_SCL), J13.15 (I2C3_SCL); also elsewhere on the board
I2C3_SDA: J1.17 (I2C3_SDA), J13.17 (I2C3_SDA); also elsewhere on the board
MOD_IRQ_A: J13.27 (MOD_IRQ_N); also elsewhere on the board
MOD_IRQ_B: J1.27 (MOD_IRQ_N); also elsewhere on the board
MOD_RESET_A: J13.29 (MOD_RESET_N); also elsewhere on the board
MOD_RESET_B: J1.29 (MOD_RESET_N); also elsewhere on the board
SPI4_CS_1: J1.11 (SPI4_CS_1), J13.11 (SPI4_CS_1); also elsewhere on the board
SPI4_CS_2: J1.13 (SPI4_CS_2), J13.13 (SPI4_CS_2); also elsewhere on the board
SPI4_MISO: J1.9 (SPI4_MISO), J13.9 (SPI4_MISO); also elsewhere on the board
SPI4_MOSI: J1.7 (SPI4_MOSI), J13.7 (SPI4_MOSI); also elsewhere on the board
SPI4_SCK: J1.5 (SPI4_SCK), J13.5 (SPI4_SCK); also elsewhere on the board
SPI6_CS_1: J1.42 (SPI6_CS_1), J13.42 (SPI6_CS_1); also elsewhere on the board
SPI6_CS_2: J1.44 (SPI6_CS_2), J13.44 (SPI6_CS_2); also elsewhere on the board
SPI6_MISO: J1.40 (SPI6_MISO), J13.40 (SPI6_MISO); also elsewhere on the board
SPI6_MOSI: J1.38 (SPI6_MOSI), J13.38 (SPI6_MOSI); also elsewhere on the board
SPI6_SCK: J1.36 (SPI6_SCK), J13.36 (SPI6_SCK); also elsewhere on the board
STACK_CS: J1.51 (STACK_CS), J13.51 (STACK_CS)
STACK_MISO: J1.49 (STACK_MISO), J13.49 (STACK_MISO)
STACK_MOSI: J1.47 (STACK_MOSI), J13.47 (STACK_MOSI)
STACK_SCK: J1.45 (STACK_SCK), J13.45 (STACK_SCK)
USART2_CTS: J1.25 (USART2_CTS), J13.25 (USART2_CTS); also elsewhere on the board
USART2_RTS: J1.23 (USART2_RTS), J13.23 (USART2_RTS); also elsewhere on the board
USART2_RX: J1.21 (USART2_RX), J13.21 (USART2_RX); also elsewhere on the board
USART2_TX: J1.19 (USART2_TX), J13.19 (USART2_TX); also elsewhere on the board
VDD_MOD_A: J13.1 (VDD_MOD), J13.2 (VDD_MOD), J13.3 (VDD_MOD), J13.4 (VDD_MOD), J13.32 (VDD_MOD), J13.34 (VDD_MOD); also elsewhere on the board
VDD_MOD_B: J1.1 (VDD_MOD), J1.2 (VDD_MOD), J1.3 (VDD_MOD), J1.4 (VDD_MOD), J1.32 (VDD_MOD), J1.34 (VDD_MOD); also elsewhere on the board

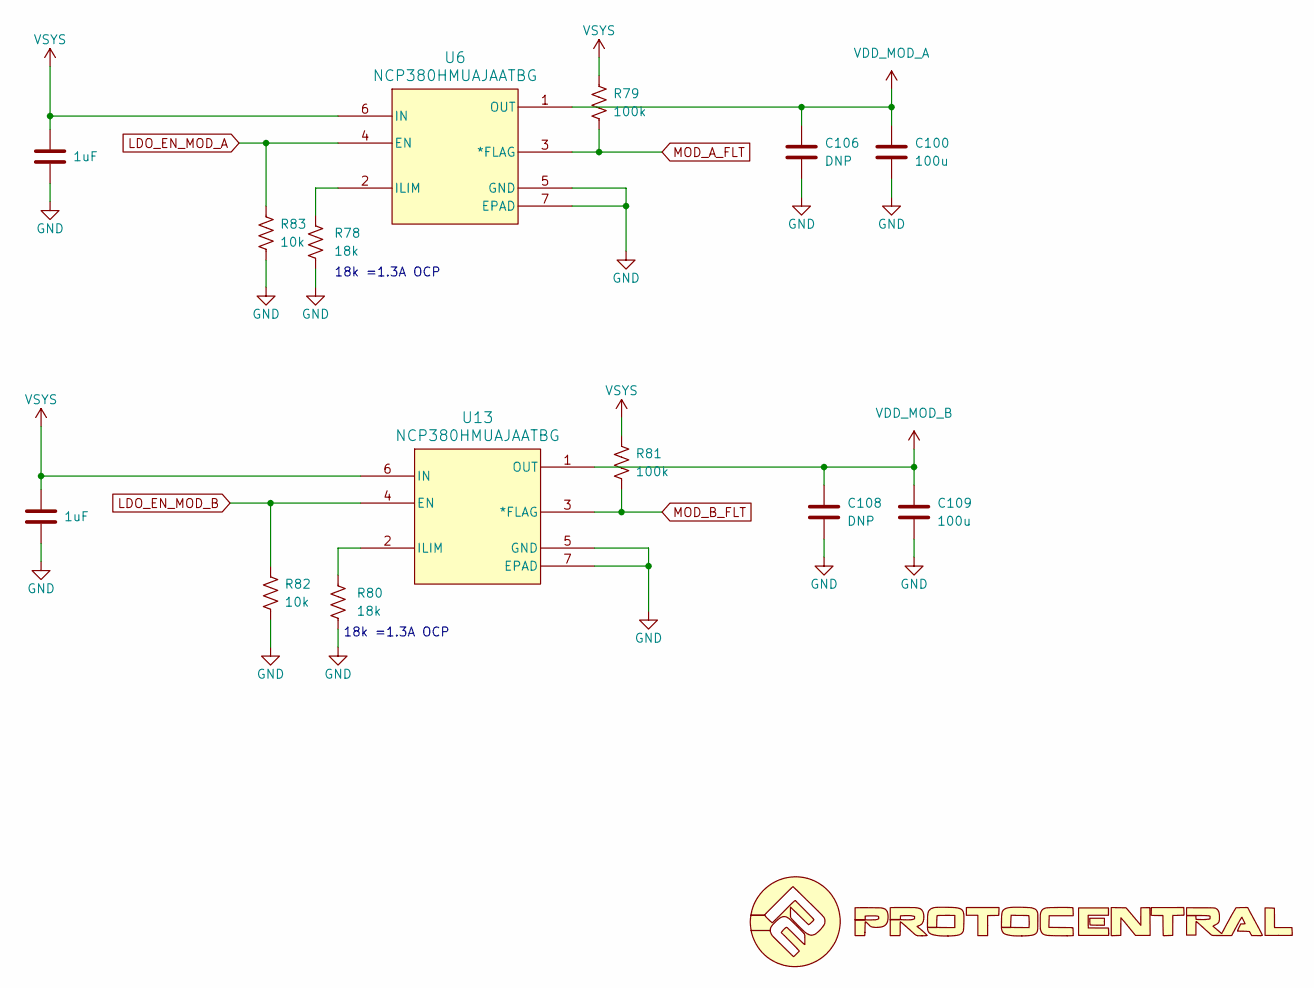
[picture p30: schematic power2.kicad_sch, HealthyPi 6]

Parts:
C75, C107: 1uF; C_0402_1005Metric; Voltage 10V; Tolerance 20%
C100, C109: 100u; C_1206_3216Metric
C106, C108: DNP; C_0805_2012Metric
R78, R80: 18k; R_0402_1005Metric
R79, R81: 100k; R_0402_1005Metric
R82, R83: 10k; R_0402_1005Metric
U6, U13: NCP380HMUAJAATBG; UDFN6_2X2_ONS
U24: LOGO

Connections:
GND: C75.2, C100.2, C106.2, C107.2, C108.2, C109.2, R78.1, R80.1, R82.1, R83.1, U6.5 (GND), U6.7 (EPAD), U13.5 (GND), U13.7 (EPAD); also elsewhere on the board
LDO_EN_MOD_A: R83.2, U6.4 (EN); also elsewhere on the board
LDO_EN_MOD_B: R82.2, U13.4 (EN); also elsewhere on the board
MOD_A_FLT: R79.1, U6.3 (*FLAG); also elsewhere on the board
MOD_B_FLT: R81.1, U13.3 (*FLAG); also elsewhere on the board
unnamed: R78.2, U6.2 (ILIM)
unnamed: R80.2, U13.2 (ILIM)
VDD_MOD_A: C100.1, C106.1, U6.1 (OUT); also elsewhere on the board
VDD_MOD_B: C108.1, C109.1, U13.1 (OUT); also elsewhere on the board
VSYS: C75.1, C107.1, R79.2, R81.2, U6.6 (IN), U13.6 (IN); also elsewhere on the board

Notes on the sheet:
18k =1.3A OCP

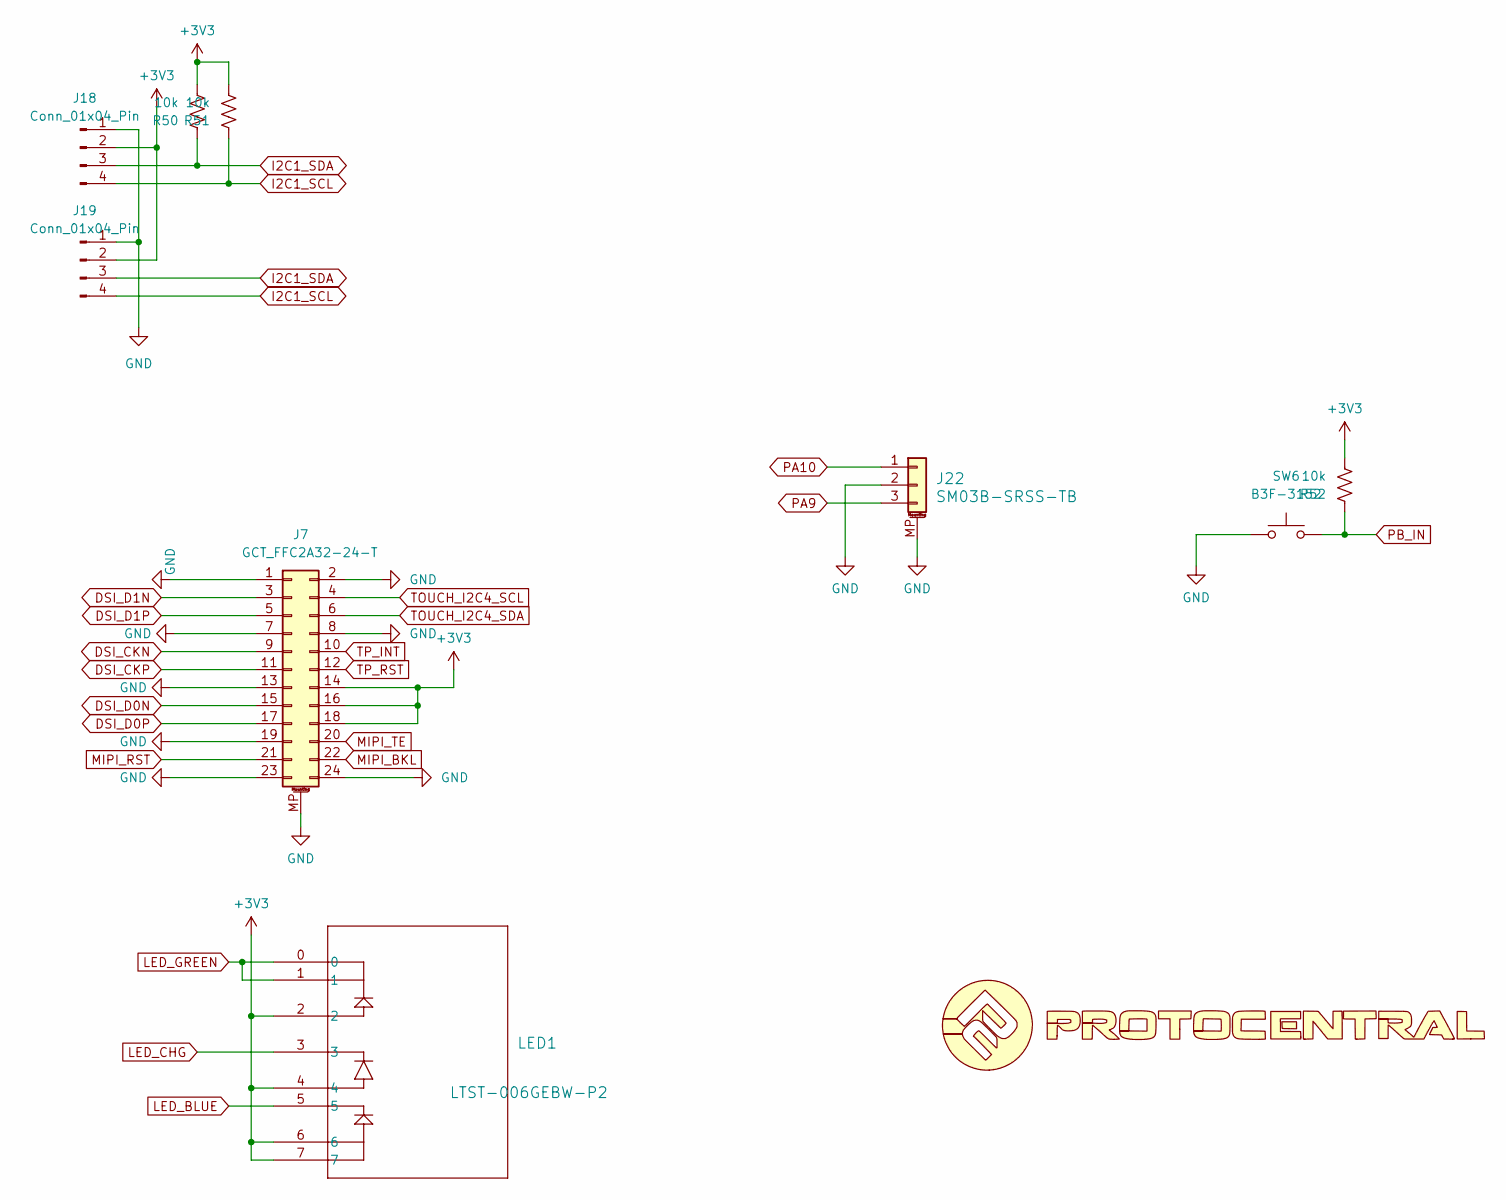
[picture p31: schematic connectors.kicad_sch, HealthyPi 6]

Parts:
J7: GCT_FFC2A32-24-T
J18, J19: Conn_01x04_Pin; JST_SH_SM04B-SRSS-TB_1x04-1MP_P1.00mm_Horizontal
J22: SM03B-SRSS-TB; JST_SH_SM03B-SRSS-TB_1x03-1MP_P1.00mm_Horizontal
LED1: LTST-006GEBW-P2; LTST-008BGEW_LTO
R50, R51, R52: 10k; R_0402_1005Metric
SW6: B3F-3152; SW_SPST_Omron_B3F-315x_Angled
U22: LOGO

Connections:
+3V3: J7.14, J7.16, J7.18, J18.2, J19.2, LED1.2, LED1.4, LED1.6, LED1.7, R50.2, R51.2, R52.2; also elsewhere on the board
DSI_CKN: J7.9; also elsewhere on the board
DSI_CKP: J7.11; also elsewhere on the board
DSI_D0N: J7.15; also elsewhere on the board
DSI_D0P: J7.17; also elsewhere on the board
DSI_D1N: J7.3; also elsewhere on the board
DSI_D1P: J7.5; also elsewhere on the board
GND: J7.1, J7.2, J7.7, J7.8, J7.13, J7.19, J7.23, J7.24, J7.MP (MountPin), J18.1, J19.1, J22.2, J22.MP (MountPin), SW6.1; also elsewhere on the board
I2C1_SCL: J18.4, J19.4, R51.1; also elsewhere on the board
I2C1_SDA: J18.3, J19.3, R50.1; also elsewhere on the board
LED_BLUE: LED1.5; also elsewhere on the board
LED_CHG: LED1.3; also elsewhere on the board
LED_GREEN: LED1.0, LED1.1; also elsewhere on the board
MIPI_BKL: J7.22; also elsewhere on the board
MIPI_RST: J7.21; also elsewhere on the board
MIPI_TE: J7.20; also elsewhere on the board
PA9: J22.3; also elsewhere on the board
PA10: J22.1; also elsewhere on the board
PB_IN: R52.1, SW6.2; also elsewhere on the board
TOUCH_I2C4_SCL: J7.4; also elsewhere on the board
TOUCH_I2C4_SDA: J7.6; also elsewhere on the board
TP_INT: J7.10; also elsewhere on the board
TP_RST: J7.12; also elsewhere on the board

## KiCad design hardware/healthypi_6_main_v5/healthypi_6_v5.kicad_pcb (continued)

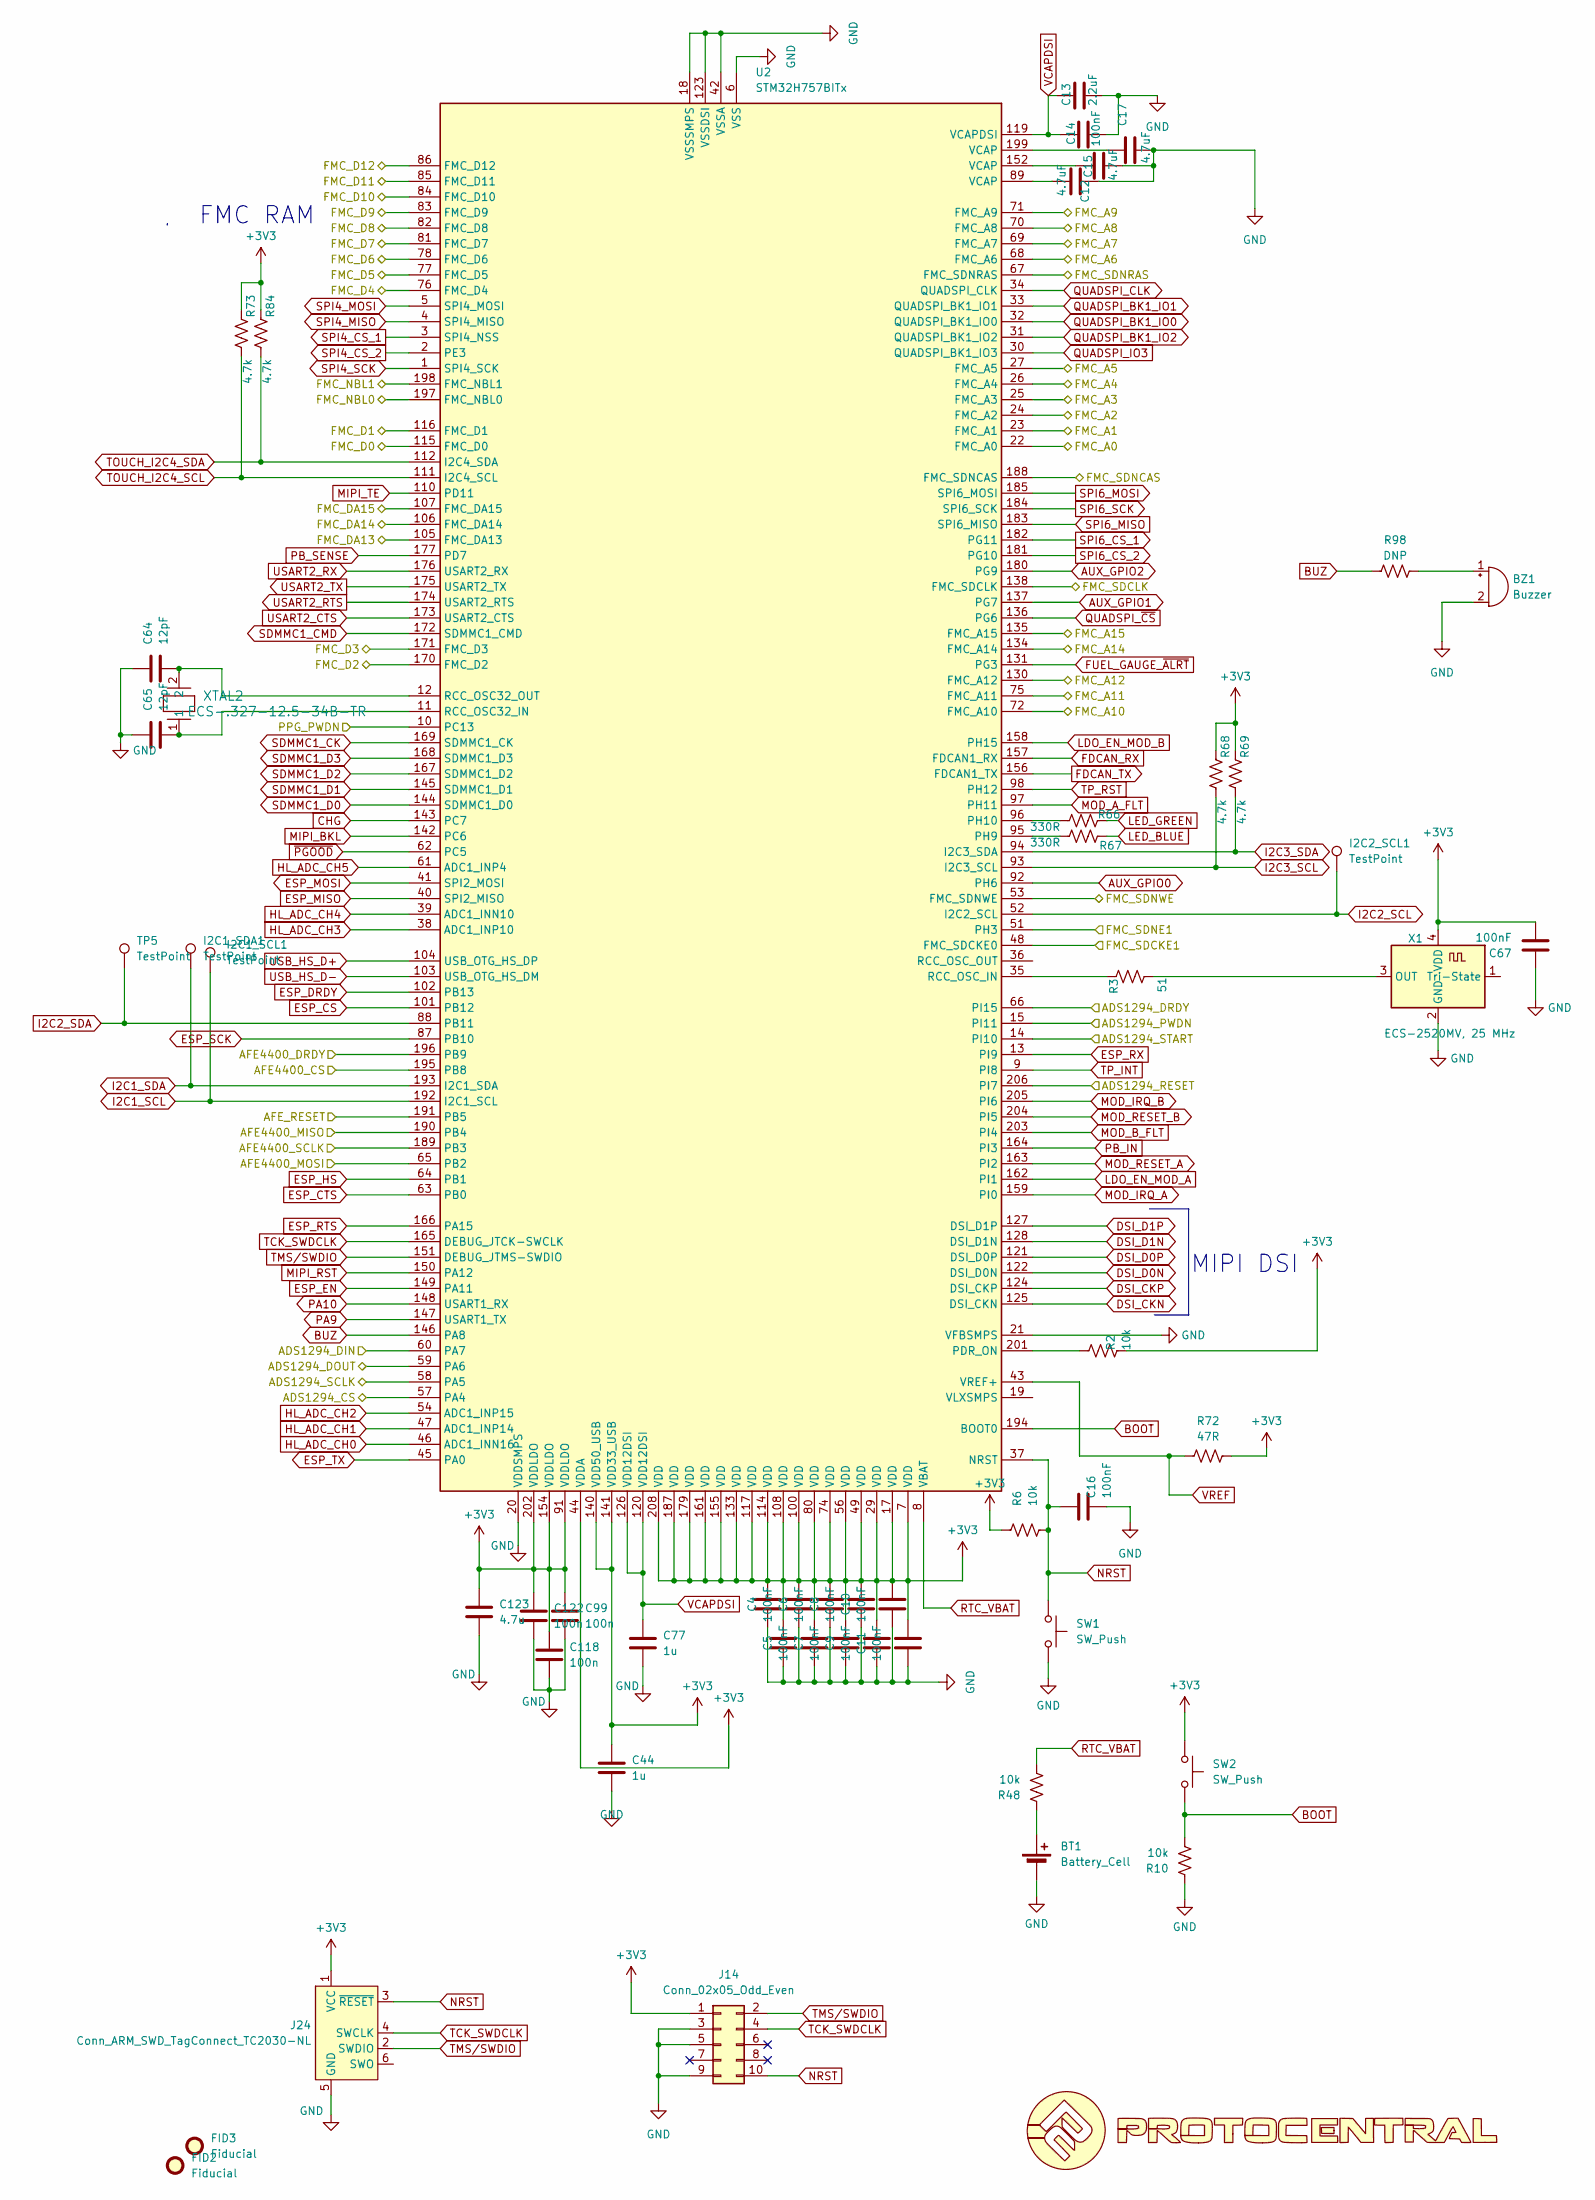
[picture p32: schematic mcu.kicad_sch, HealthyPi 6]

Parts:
BT1: Battery_Cell; BatteryHolder_Keystone_3001_1x12mm
BZ1: Buzzer; Buzzer_Murata_PKMCS0909E
C2, C3, C4, C5, C6, C7, C8, C9, C10, C11, C14, C16, C67: 100nF; C_0402_1005Metric
C12, C15, C17: 4.7uF; C_0402_1005Metric
C13: 2.2uF; C_0402_1005Metric
C44, C77: 1u; C_0402_1005Metric
C64, C65: 12pF; C_0402_1005Metric
C99, C118, C122: 100n; C_0402_1005Metric
C123: 4.7u; C_0402_1005Metric
FID2, FID3: Fiducial; Fiducial_1mm_Mask3mm
I2C1_SCL1, I2C1_SDA1, I2C2_SCL1: TestPoint; TestPoint_Pad_D1.0mm
J14: Conn_02x05_Odd_Even; PinHeader_2x05_P1.27mm_Vertical_SMD
J24: Conn_ARM_SWD_TagConnect_TC2030-NL; Tag-Connect_TC2030-IDC-NL_2x03_P1.27mm_Vertical
R2, R6, R10, R48: 10k; R_0402_1005Metric
R3: 51; R_0402_1005Metric
R66, R67: 330R; R_0402_1005Metric
R68, R69, R73, R84: 4.7k; R_0402_1005Metric
R72: 47R; R_0402_1005Metric
R98: DNP; R_0402_1005Metric
SW1, SW2: SW_Push; SW_Push_1P1T_NO_CK_KMR2
TP5: TestPoint; TestPoint_Pad_D1.0mm
U2: STM32H757BITx; LQFP-208_28x28mm_P0.5mm
U10: LOGO
X1: ECS-2520MV, 25 MHz; Oscillator_SMD_ECS_2520MV-xxx-xx-4Pin_2.5x2.0mm
XTAL2: ECS-.327-12.5-34B-TR; XTAL_ECS-31B_ECS

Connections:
+3V3: C2.2, C3.2, C4.2, C5.2, C6.2, C7.2, C8.2, C9.2, C10.2, C11.2, C44.1, C67.2, C99.1, C118.1, C122.1, C123.1, J14.1, J24.1 (VCC), R2.2, R6.1, R68.2, R69.2, R72.1, R73.2, R84.2, SW2.1, U2.7 (VDD), U2.17 (VDD), U2.29 (VDD), U2.44 (VDDA), U2.49 (VDD), U2.56 (VDD), U2.74 (VDD), U2.80 (VDD), U2.91 (VDDLDO), U2.100 (VDD), U2.108 (VDD), U2.114 (VDD), U2.117 (VDD), U2.133 (VDD), U2.140 (VDD50_USB), U2.141 (VDD33_USB), U2.154 (VDDLDO), U2.155 (VDD), U2.161 (VDD), U2.179 (VDD), U2.187 (VDD), U2.202 (VDDLDO), U2.208 (VDD), X1.4 (VDD); also elsewhere on the board
/ECG Frontend/ADS1294_CS: U2.57 (PA4); also elsewhere on the board
/ECG Frontend/ADS1294_DIN: U2.60 (PA7); also elsewhere on the board
/ECG Frontend/ADS1294_DOUT: U2.59 (PA6); also elsewhere on the board
/ECG Frontend/ADS1294_DRDY: U2.66 (PI15); also elsewhere on the board
/ECG Frontend/ADS1294_PWDN: U2.15 (PI11); also elsewhere on the board
/ECG Frontend/ADS1294_RESET: U2.206 (PI7); also elsewhere on the board
/ECG Frontend/ADS1294_SCLK: U2.58 (PA5); also elsewhere on the board
/ECG Frontend/ADS1294_START: U2.14 (PI10); also elsewhere on the board
/MCU/AFE4400_CS: U2.195 (PB8); also elsewhere on the board
/MCU/AFE4400_DRDY: U2.196 (PB9); also elsewhere on the board
/MCU/AFE4400_MISO: U2.190 (PB4); also elsewhere on the board
/MCU/AFE4400_MOSI: U2.65 (PB2); also elsewhere on the board
/MCU/AFE4400_SCLK: U2.189 (PB3); also elsewhere on the board
/MCU/AFE_RESET: U2.191 (PB5); also elsewhere on the board
/MCU/FMC_A0: U2.22 (FMC_A0); also elsewhere on the board
/MCU/FMC_A1: U2.23 (FMC_A1); also elsewhere on the board
/MCU/FMC_A2: U2.24 (FMC_A2); also elsewhere on the board
/MCU/FMC_A3: U2.25 (FMC_A3); also elsewhere on the board
/MCU/FMC_A4: U2.26 (FMC_A4); also elsewhere on the board
/MCU/FMC_A5: U2.27 (FMC_A5); also elsewhere on the board
/MCU/FMC_A6: U2.68 (FMC_A6); also elsewhere on the board
/MCU/FMC_A7: U2.69 (FMC_A7); also elsewhere on the board
/MCU/FMC_A8: U2.70 (FMC_A8); also elsewhere on the board
/MCU/FMC_A9: U2.71 (FMC_A9); also elsewhere on the board
/MCU/FMC_A10: U2.72 (FMC_A10); also elsewhere on the board
/MCU/FMC_A11: U2.75 (FMC_A11); also elsewhere on the board
/MCU/FMC_A12: U2.130 (FMC_A12); also elsewhere on the board
/MCU/FMC_A14: U2.134 (FMC_A14); also elsewhere on the board
/MCU/FMC_A15: U2.135 (FMC_A15); also elsewhere on the board
/MCU/FMC_D0: U2.115 (FMC_D0); also elsewhere on the board
/MCU/FMC_D1: U2.116 (FMC_D1); also elsewhere on the board
/MCU/FMC_D2: U2.170 (FMC_D2); also elsewhere on the board
/MCU/FMC_D3: U2.171 (FMC_D3); also elsewhere on the board
/MCU/FMC_D4: U2.76 (FMC_D4); also elsewhere on the board
/MCU/FMC_D5: U2.77 (FMC_D5); also elsewhere on the board
/MCU/FMC_D6: U2.78 (FMC_D6); also elsewhere on the board
/MCU/FMC_D7: U2.81 (FMC_D7); also elsewhere on the board
/MCU/FMC_D8: U2.82 (FMC_D8); also elsewhere on the board
/MCU/FMC_D9: U2.83 (FMC_D9); also elsewhere on the board
/MCU/FMC_D10: U2.84 (FMC_D10); also elsewhere on the board
/MCU/FMC_D11: U2.85 (FMC_D11); also elsewhere on the board
/MCU/FMC_D12: U2.86 (FMC_D12); also elsewhere on the board
/MCU/FMC_DA13: U2.105 (FMC_DA13); also elsewhere on the board
/MCU/FMC_DA14: U2.106 (FMC_DA14); also elsewhere on the board
/MCU/FMC_DA15: U2.107 (FMC_DA15); also elsewhere on the board
/MCU/FMC_NBL0: U2.197 (FMC_NBL0); also elsewhere on the board
/MCU/FMC_NBL1: U2.198 (FMC_NBL1); also elsewhere on the board
/MCU/FMC_SDCKE1: U2.48 (FMC_SDCKE0); also elsewhere on the board
/MCU/FMC_SDCLK: U2.138 (FMC_SDCLK); also elsewhere on the board
/MCU/FMC_SDNCAS: U2.188 (FMC_SDNCAS); also elsewhere on the board
/MCU/FMC_SDNE1: U2.51 (PH3); also elsewhere on the board
/MCU/FMC_SDNRAS: U2.67 (FMC_SDNRAS); also elsewhere on the board
/MCU/FMC_SDNWE: U2.53 (FMC_SDNWE); also elsewhere on the board
/MCU/PPG_PWDN: U2.10 (PC13); also elsewhere on the board
AUX_GPIO0: U2.92 (PH6); also elsewhere on the board
AUX_GPIO1: U2.137 (PG7); also elsewhere on the board
AUX_GPIO2: U2.180 (PG9); also elsewhere on the board
BOOT: R10.2, SW2.2, U2.194 (BOOT0)
BUZ: R98.1, U2.146 (PA8)
CHG: U2.143 (PC7); also elsewhere on the board
DSI_CKN: U2.125 (DSI_CKN); also elsewhere on the board
DSI_CKP: U2.124 (DSI_CKP); also elsewhere on the board
DSI_D0N: U2.122 (DSI_D0N); also elsewhere on the board
DSI_D0P: U2.121 (DSI_D0P); also elsewhere on the board
DSI_D1N: U2.128 (DSI_D1N); also elsewhere on the board
DSI_D1P: U2.127 (DSI_D1P); also elsewhere on the board
ESP_CS: U2.101 (PB12); also elsewhere on the board
ESP_CTS: U2.63 (PB0); also elsewhere on the board
ESP_DRDY: U2.102 (PB13); also elsewhere on the board
ESP_EN: U2.149 (PA11); also elsewhere on the board
ESP_HS: U2.64 (PB1); also elsewhere on the board
ESP_MISO: U2.40 (SPI2_MISO); also elsewhere on the board
ESP_MOSI: U2.41 (SPI2_MOSI); also elsewhere on the board
ESP_RTS: U2.166 (PA15); also elsewhere on the board
ESP_RX: U2.13 (PI9); also elsewhere on the board
ESP_SCK: U2.87 (PB10); also elsewhere on the board
ESP_TX: U2.45 (PA0); also elsewhere on the board
FDCAN_RX: U2.157 (FDCAN1_RX); also elsewhere on the board
FDCAN_TX: U2.156 (FDCAN1_TX); also elsewhere on the board
FUEL_GAUGE_~ALRT: U2.131 (PG3); also elsewhere on the board
GND: BT1.2 (-), BZ1.2 (-), C2.1, C3.1, C4.1, C5.1, C6.1, C7.1, C8.1, C9.1, C10.1, C11.1, C12.2, C13.2, C14.2, C15.2, C16.2, C17.2, C44.2, C64.1, C65.1, C67.1, C77.2, C99.2, C118.2, C122.2, C123.2, J14.3, J14.5, J14.9, J24.5 (GND), R10.1, SW1.2, U2.6 (VSS), U2.16 (VSS), U2.18 (VSSSMPS), U2.20 (VDDSMPS), U2.21 (VFBSMPS), U2.28 (VSS), U2.42 (VSSA), U2.50 (VSS), U2.55 (VSS), U2.73 (VSS), U2.79 (VSS), U2.90 (VSS), U2.99 (VSS), U2.109 (VSS), U2.113 (VSS), U2.118 (VSS), U2.123 (VSSDSI), U2.129 (VSSDSI), U2.132 (VSS), U2.139 (VSS), U2.153 (VSS), U2.160 (VSS), U2.178 (VSS), U2.186 (VSS), U2.200 (VSS), U2.207 (VSS), X1.2 (GND); also elsewhere on the board
HL_ADC_CH0: U2.46 (ADC1_INN16); also elsewhere on the board
HL_ADC_CH1: U2.47 (ADC1_INP14); also elsewhere on the board
HL_ADC_CH2: U2.54 (ADC1_INP15); also elsewhere on the board
HL_ADC_CH3: U2.38 (ADC1_INP10); also elsewhere on the board
HL_ADC_CH4: U2.39 (ADC1_INN10); also elsewhere on the board
HL_ADC_CH5: U2.61 (ADC1_INP4); also elsewhere on the board
I2C1_SCL: I2C1_SCL1.1 (1_1), U2.192 (I2C1_SCL); also elsewhere on the board
I2C1_SDA: I2C1_SDA1.1 (1_1), U2.193 (I2C1_SDA); also elsewhere on the board
I2C2_SCL: I2C2_SCL1.1 (1_1), U2.52 (I2C2_SCL); also elsewhere on the board
I2C2_SDA: TP5.1 (1_1), U2.88 (PB11); also elsewhere on the board
I2C3_SCL: R68.1, U2.93 (I2C3_SCL); also elsewhere on the board
I2C3_SDA: R69.1, U2.94 (I2C3_SDA); also elsewhere on the board
LDO_EN_MOD_A: U2.162 (PI1); also elsewhere on the board
LDO_EN_MOD_B: U2.158 (PH15); also elsewhere on the board
LED_BLUE: R67.2; also elsewhere on the board
LED_GREEN: R66.2; also elsewhere on the board
MIPI_BKL: U2.142 (PC6); also elsewhere on the board
MIPI_RST: U2.150 (PA12); also elsewhere on the board
MIPI_TE: U2.110 (PD11); also elsewhere on the board
MOD_A_FLT: U2.97 (PH11); also elsewhere on the board
MOD_B_FLT: U2.203 (PI4); also elsewhere on the board
MOD_IRQ_A: U2.159 (PI0); also elsewhere on the board
MOD_IRQ_B: U2.205 (PI6); also elsewhere on the board
MOD_RESET_A: U2.163 (PI2); also elsewhere on the board
MOD_RESET_B: U2.204 (PI5); also elsewhere on the board
NRST: C16.1, J14.10, J24.3 (~RESET), R6.2, SW1.1, U2.37 (NRST)
unnamed: BT1.1 (+), R48.1
unnamed: BZ1.1 (+), R98.2
unnamed: C12.1, U2.89 (VCAP)
unnamed: C15.1, U2.152 (VCAP)
unnamed: C17.1, U2.199 (VCAP)
unnamed: C65.2, U2.11 (RCC_OSC32_IN), XTAL2.1
unnamed: C64.2, U2.12 (RCC_OSC32_OUT), XTAL2.2
unnamed: R2.1, U2.201 (PDR_ON)
unnamed: R3.1, U2.35 (RCC_OSC_IN)
unnamed: R67.1, U2.95 (PH9)
unnamed: R66.1, U2.96 (PH10)
unnamed: R3.2, X1.3 (OUT)
PA9: U2.147 (USART1_TX); also elsewhere on the board
PA10: U2.148 (USART1_RX); also elsewhere on the board
PB_IN: U2.164 (PI3); also elsewhere on the board
PB_SENSE: U2.177 (PD7)
QUADSPI_BK1_IO0: U2.32 (QUADSPI_BK1_IO0); also elsewhere on the board
QUADSPI_BK1_IO1: U2.33 (QUADSPI_BK1_IO1); also elsewhere on the board
QUADSPI_BK1_IO2: U2.31 (QUADSPI_BK1_IO2); also elsewhere on the board
QUADSPI_CLK: U2.34 (QUADSPI_CLK); also elsewhere on the board
QUADSPI_IO3: U2.30 (QUADSPI_BK1_IO3); also elsewhere on the board
QUADSPI_~CS: U2.136 (PG6); also elsewhere on the board
RTC_VBAT: R48.2, U2.8 (VBAT)
SDMMC1_CK: U2.169 (SDMMC1_CK); also elsewhere on the board
SDMMC1_CMD: U2.172 (SDMMC1_CMD); also elsewhere on the board
SDMMC1_D0: U2.144 (SDMMC1_D0); also elsewhere on the board
SDMMC1_D1: U2.145 (SDMMC1_D1); also elsewhere on the board
SDMMC1_D2: U2.167 (SDMMC1_D2); also elsewhere on the board
SDMMC1_D3: U2.168 (SDMMC1_D3); also elsewhere on the board
SPI4_CS_1: U2.3 (SPI4_NSS); also elsewhere on the board
SPI4_CS_2: U2.2 (PE3); also elsewhere on the board
SPI4_MISO: U2.4 (SPI4_MISO); also elsewhere on the board
SPI4_MOSI: U2.5 (SPI4_MOSI); also elsewhere on the board
SPI4_SCK: U2.1 (SPI4_SCK); also elsewhere on the board
SPI6_CS_1: U2.182 (PG11); also elsewhere on the board
SPI6_CS_2: U2.181 (PG10); also elsewhere on the board
SPI6_MISO: U2.183 (SPI6_MISO); also elsewhere on the board
SPI6_MOSI: U2.185 (SPI6_MOSI); also elsewhere on the board
SPI6_SCK: U2.184 (SPI6_SCK); also elsewhere on the board
TCK_SWDCLK: J14.4, J24.4 (SWCLK), U2.165 (DEBUG_JTCK-SWCLK)
TMS/SWDIO: J14.2, J24.2 (SWDIO), U2.151 (DEBUG_JTMS-SWDIO)
TOUCH_I2C4_SCL: R73.1, U2.111 (I2C4_SCL); also elsewhere on the board
TOUCH_I2C4_SDA: R84.1, U2.112 (I2C4_SDA); also elsewhere on the board
TP_INT: U2.9 (PI8); also elsewhere on the board
TP_RST: U2.98 (PH12); also elsewhere on the board
USART2_CTS: U2.173 (USART2_CTS); also elsewhere on the board
USART2_RTS: U2.174 (USART2_RTS); also elsewhere on the board
USART2_RX: U2.176 (USART2_RX); also elsewhere on the board
USART2_TX: U2.175 (USART2_TX); also elsewhere on the board
USB_HS_D+: U2.104 (USB_OTG_HS_DP); also elsewhere on the board
USB_HS_D-: U2.103 (USB_OTG_HS_DM); also elsewhere on the board
VCAPDSI: C13.1, C14.1, C77.1, U2.119 (VCAPDSI), U2.120 (VDD12DSI), U2.126 (VDD12DSI)
VREF: R72.2, U2.43 (VREF+)
~PGOOD: U2.62 (PC5); also elsewhere on the board

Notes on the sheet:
FMC RAM
MIPI DSI

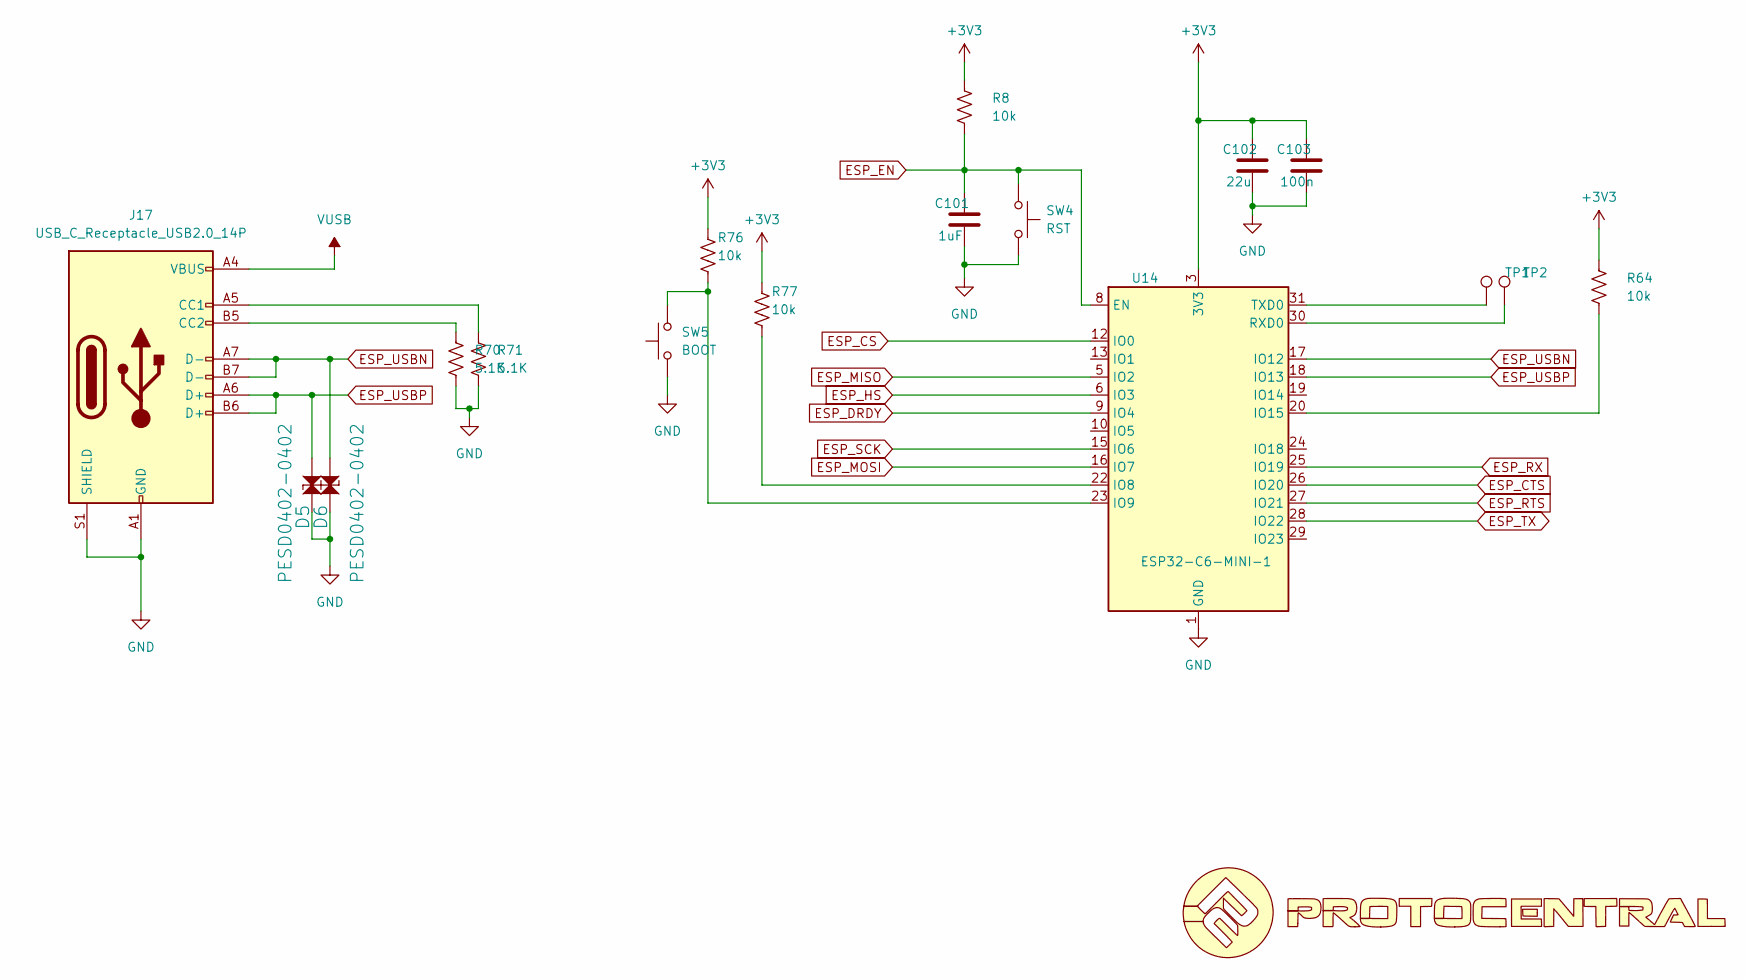
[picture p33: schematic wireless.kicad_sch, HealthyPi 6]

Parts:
C101: 1uF; C_0402_1005Metric
C102: 22u; C_0805_2012Metric
C103: 100n; C_0402_1005Metric
D5, D6: PESD0402-0402; D_SOD-882D
J17: USB_C_Receptacle_USB2.0_14P; USB_C_Receptacle_GCT_USB4105-xx-A_16P_TopMnt_Horizontal
R8, R64, R76, R77: 10k; R_0402_1005Metric
R70, R71: 5.1K; R_0402_1005Metric
SW4: RST; SW_Push_1P1T_NO_CK_KMR2
SW5: BOOT; SW_Push_1P1T_NO_CK_KMR2
TP1, TP2: TestPoint; TestPoint_Pad_1.0x1.0mm
U14: ESP32-C6-MINI-1
U20: LOGO

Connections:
+3V3: C102.2, C103.2, R8.1, R64.1, R76.1, R77.1, U14.3 (3V3); also elsewhere on the board
ESP_CS: U14.12 (IO0); also elsewhere on the board
ESP_CTS: U14.26 (IO20); also elsewhere on the board
ESP_DRDY: U14.9 (IO4); also elsewhere on the board
ESP_EN: C101.2, R8.2, SW4.1, U14.8 (EN); also elsewhere on the board
ESP_HS: U14.6 (IO3); also elsewhere on the board
ESP_MISO: U14.5 (IO2); also elsewhere on the board
ESP_MOSI: U14.16 (IO7); also elsewhere on the board
ESP_RTS: U14.27 (IO21); also elsewhere on the board
ESP_RX: U14.25 (IO19); also elsewhere on the board
ESP_SCK: U14.15 (IO6); also elsewhere on the board
ESP_TX: U14.28 (IO22); also elsewhere on the board
ESP_USBN: D6.2, J17.A7 (D-), J17.B7 (D-), U14.17 (IO12)
ESP_USBP: D5.2, J17.A6 (D+), J17.B6 (D+), U14.18 (IO13)
GND: C101.1, C102.1, C103.1, D5.1, D6.1, J17.A1 (GND), J17.A12 (GND), J17.B1 (GND), J17.B12 (GND), J17.S1 (SHIELD), R70.1, R71.2, SW4.2, SW5.1, U14.1 (GND), U14.2 (GND), U14.11 (GND), U14.14 (GND), U14.36 (GND), U14.37 (GND), U14.38 (GND), U14.39 (GND), U14.40 (GND), U14.41 (GND), U14.42 (GND), U14.43 (GND), U14.44 (GND), U14.45 (GND), U14.46 (GND), U14.47 (GND), U14.48 (GND), U14.49 (GND), U14.50 (GND), U14.51 (GND), U14.52 (GND), U14.53 (GND); also elsewhere on the board
unnamed: J17.A5 (CC1), R71.1
unnamed: J17.B5 (CC2), R70.2
unnamed: R77.2, U14.22 (IO8)
unnamed: R76.2, SW5.2, U14.23 (IO9)
unnamed: R64.2, U14.20 (IO15)
unnamed: TP2.1 (1_1), U14.30 (RXD0)
unnamed: TP1.1 (1_1), U14.31 (TXD0)
VUSB: J17.A4 (VBUS), J17.A9 (VBUS), J17.B4 (VBUS), J17.B9 (VBUS); also elsewhere on the board

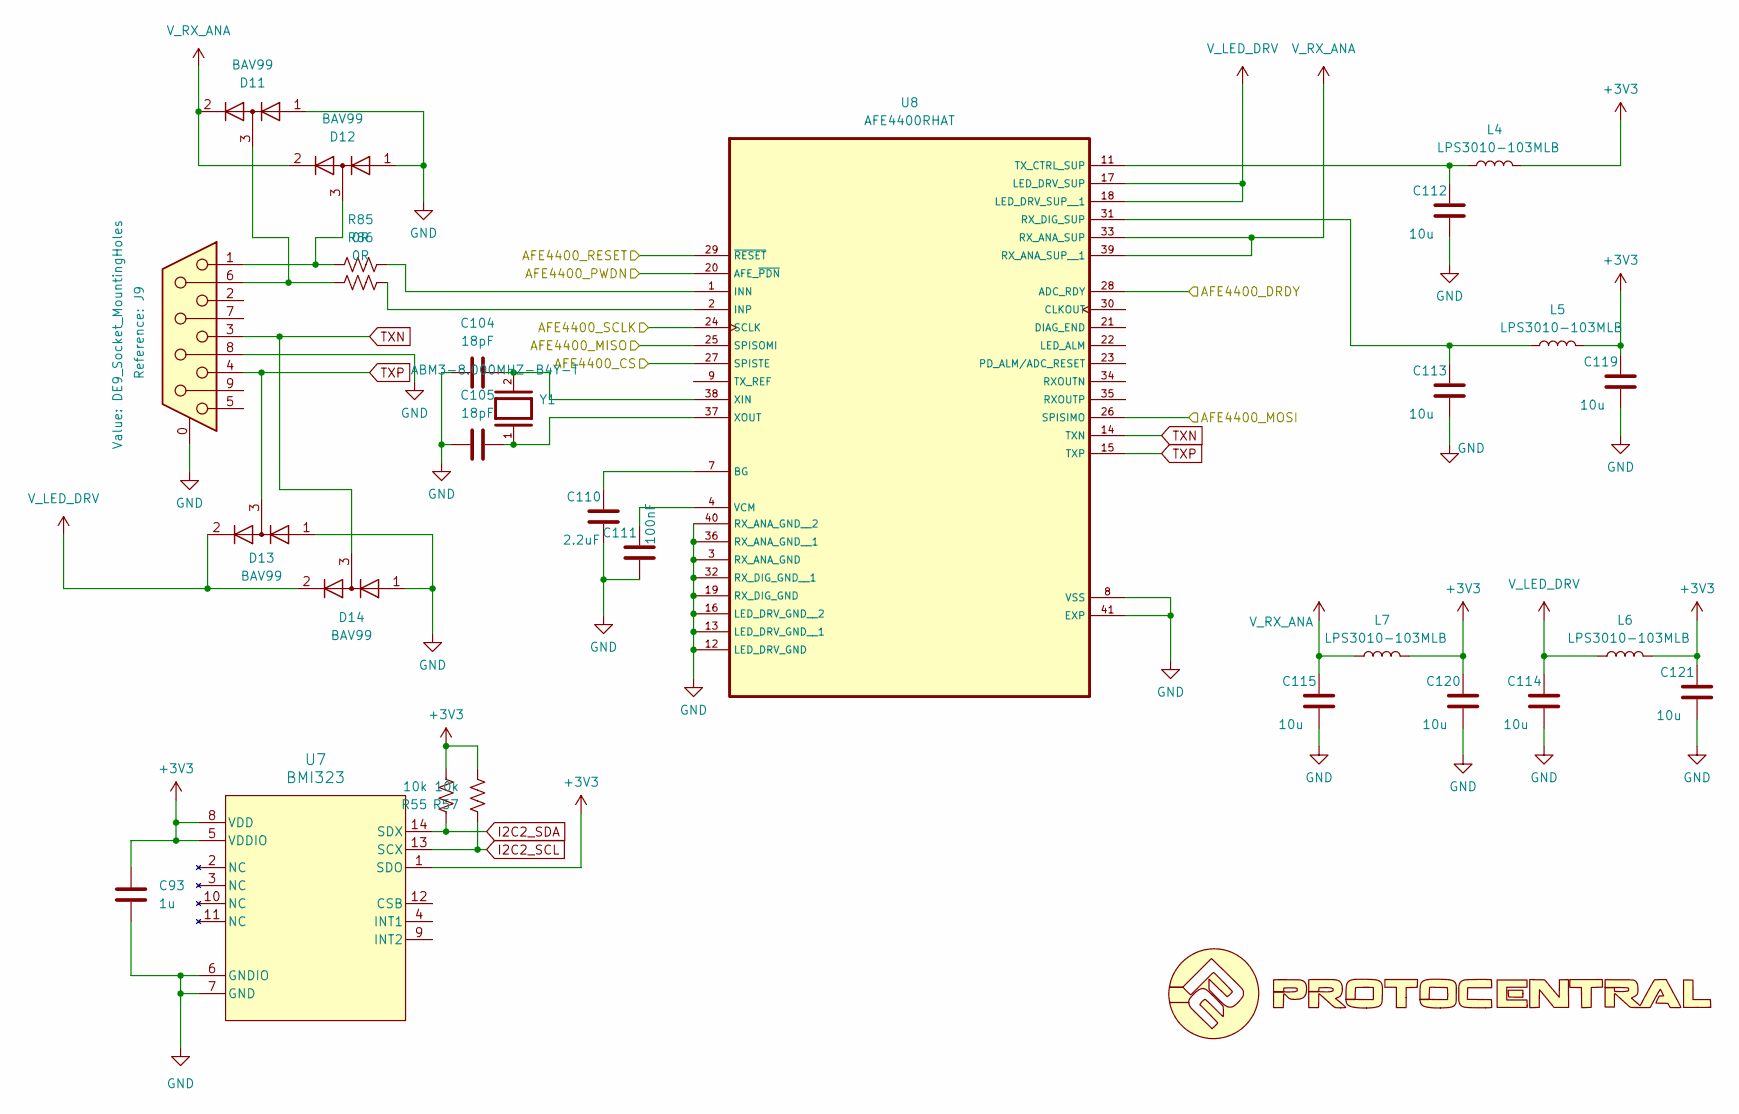
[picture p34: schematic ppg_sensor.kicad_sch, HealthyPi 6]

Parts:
C93: 1u; C_0402_1005Metric
C104, C105: 18pF; C_0402_1005Metric
C110: 2.2uF; C_0402_1005Metric
C111: 100nF; C_0402_1005Metric
C112, C113, C114, C115, C119, C120, C121: 10u; C_0805_2012Metric
D11, D12, D13, D14: BAV99; SOT-23
J9: DE9_Socket_MountingHoles; DSUB-9_Pins_Horizontal_P2.77x2.84mm_EdgePinOffset7.70mm_Hou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
L4, L5, L6, L7: LPS3010-103MLB; L_Coilcraft_LPS3010
R55, R57: 10k; R_0402_1005Metric
R85, R86: 0R; R_0402_1005Metric
U7: BMI323; BMI323_BOS
U8: AFE4400RHAT; Texas_RHA_VQFN-40-1EP_6x6mm_P0.5mm_EP4.6x4.6mm_ThermalVias
U19: LOGO
Y1: ABM3-8.000MHZ-B4Y-T; XTAL_ABM3-8.000MHZ-B4Y-T; PARTREV 4/25/2022

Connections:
+3V3: C93.2, C119.1, C120.1, C121.1, L4.2, L5.2, L6.2, L7.2, R55.2, R57.2, U7.1 (SDO), U7.5 (VDDIO), U7.8 (VDD); also elsewhere on the board
/MCU/AFE4400_CS: U8.27 (SPISTE); also elsewhere on the board
/MCU/AFE4400_DRDY: U8.28 (ADC_RDY); also elsewhere on the board
/MCU/AFE4400_MISO: U8.25 (SPISOMI); also elsewhere on the board
/MCU/AFE4400_MOSI: U8.26 (SPISIMO); also elsewhere on the board
/MCU/AFE4400_SCLK: U8.24 (SCLK); also elsewhere on the board
/MCU/AFE_RESET: U8.29 (~RESET); also elsewhere on the board
/MCU/PPG_PWDN: U8.20 (AFE_~PDN); also elsewhere on the board
GND: C93.1, C104.2, C105.2, C110.2, C111.2, C112.2, C113.2, C114.2, C115.2, C119.2, C120.2, C121.2, D11.1 (K), D12.1 (K), D13.1 (K), D14.1 (K), J9.0 (PAD), J9.8, U7.6 (GNDIO), U7.7 (GND), U8.3 (RX_ANA_GND), U8.8 (VSS), U8.12 (LED_DRV_GND), U8.13 (LED_DRV_GND__1), U8.16 (LED_DRV_GND__2), U8.19 (RX_DIG_GND), U8.32 (RX_DIG_GND__1), U8.36 (RX_ANA_GND__1), U8.40 (RX_ANA_GND__2), U8.41 (EXP); also elsewhere on the board
I2C2_SCL: R57.1, U7.13 (SCX); also elsewhere on the board
I2C2_SDA: R55.1, U7.14 (SDX); also elsewhere on the board
unnamed: D11.3 (K), J9.6, R86.1
unnamed: D12.3 (K), J9.1, R85.1
unnamed: C110.1, U8.7 (BG)
unnamed: R85.2, U8.1 (INN)
unnamed: R86.2, U8.2 (INP)
unnamed: C113.1, L5.1, U8.31 (RX_DIG_SUP)
unnamed: C112.1, L4.1, U8.11 (TX_CTRL_SUP)
unnamed: C111.1, U8.4 (VCM)
unnamed: C104.1, U8.38 (XIN), Y1.2
unnamed: C105.1, U8.37 (XOUT), Y1.1
TXN: D14.3 (K), J9.3, U8.14 (TXN)
TXP: D13.3 (K), J9.4, U8.15 (TXP)
V_LED_DRV: C114.1, D13.2 (A), D14.2 (A), L6.1, U8.17 (LED_DRV_SUP), U8.18 (LED_DRV_SUP__1)
V_RX_ANA: C115.1, D11.2 (A), D12.2 (A), L7.1, U8.33 (RX_ANA_SUP), U8.39 (RX_ANA_SUP__1)

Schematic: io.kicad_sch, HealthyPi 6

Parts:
C66, C79: 1u; C_0805_2012Metric
C68: 10uF /16V; C_0805_2012Metric
C69: 22u; C_0805_2012Metric
C70: 100nF; C_0402_1005Metric
C71: 100nF / 16V; C_0402_1005Metric
C74: 4.7u; C_0805_2012Metric
C78, C89: 100n; C_0805_2012Metric
CR1: ESDA25W; SOT-323_SC-70
CR2: ESDA25P35-1U1M; ST_QFN-2L_1.6x1.0mm
D1, D2: PESD0402-0402; D_SOD-882D
D3: SMAJ6.0CA; D_SMA
J3: USB_C_Receptacle_USB2.0_14P; USB_C_Receptacle_GCT_USB4105-xx-A_16P_TopMnt_Horizontal
PS1: THM_10-0511; CONV_THM_10-0511; PARTREV May 17, 2024
R7, R9: 5.1k; R_0402_1005Metric
U5: ISOUSB111DWR; SOIC16_DW_TEX
U17: LOGO

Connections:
+3V3: C79.2, C89.2, U5.12 (PIN), U5.14 (V3P3V2), U5.16 (VBUS2); also elsewhere on the board
CC1: CR1.2, J3.A5 (CC1), R9.2
CC2: CR1.1, J3.B5 (CC2), R7.2
GND: C69.1, C70.1, C74.1, C79.1, C89.1, PS1.12 (-VOUT), U5.9 (GND2), U5.15 (GND2); also elsewhere on the board
unnamed: C68.2, C71.2, D3.1 (A1), PS1.1 (+VIN(VCC))
unnamed: C78.2, U5.3 (V3P3V1)
USB_D+: D1.2, J3.A6 (D+), J3.B6 (D+), U5.7 (UD+)
USB_D-: D2.2, J3.A7 (D-), J3.B7 (D-), U5.6 (UD-)
USB_HS_D+: U5.10 (DD+); also elsewhere on the board
USB_HS_D-: U5.11 (DD-); also elsewhere on the board
VBUS: C66.2, CR2.1, D3.2 (A2), J3.A4 (VBUS), J3.A9 (VBUS), J3.B4 (VBUS), J3.B9 (VBUS), U5.1 (VBUS1)
VSS: C66.1, C68.1, C71.1, C78.1, CR1.3, CR2.2, D1.1, D2.1, J3.A1 (GND), J3.A12 (GND), J3.B1 (GND), J3.B12 (GND), J3.S1 (SHIELD), PS1.23 (-VIN(GND)), PS1.24 (-VIN(GND)__1), R7.1, R9.1, U5.2 (GND1), U5.8 (GND1)
VUSB: C69.2, C70.2, C74.2, PS1.13 (+VOUT); also elsewhere on the board

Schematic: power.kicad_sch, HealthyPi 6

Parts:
3V3: TestPoint; TestPoint_Pad_D1.0mm
C50: 100nF; C_0402_1005Metric; Voltage 25V; Tolerance 20%
C57: 1u; C_0805_2012Metric
C58, C73, C95: 4.7u; C_0805_2012Metric
C94: 220u, 1206; C_1206_3216Metric
C116: 22u; C_0805_2012Metric
C117: DNP; C_0402_1005Metric
J5: JST_2mm_LiPo; JST_PH_S2B-PH-SM4-TB_1x02-1MP_P2.00mm_Horizontal
L10: DFE252012F-1R0M, 1uH; L_1008_2520Metric
R11: 1.1k; R_0402_1005Metric
R12: 590; R_0402_1005Metric
R13: R_US; R_0402_1005Metric
R14, R35: 10k; R_0402_1005Metric
R16: 1.5k; R_0402_1005Metric
R74: 453k; R_0402_1005Metric
R75: 100k; R_0402_1005Metric
SW3: SW_SPDT; SW_SPDT_CK_JS102011SAQN
U9: BQ24074RGT; VQFN-16-1EP_3x3mm_P0.5mm_EP1.6x1.6mm
U11: TPS62A02APDDC; SOT-23-6
U12: MAX17048; SON50P200X200X80-9N
U18: LOGO
VBAT1: TestPoint; TestPoint_Pad_D1.0mm
VSYS1: TestPoint; TestPoint_Pad_D1.0mm

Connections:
+3V3: 3V3.1 (1_1), C116.1, C117.2, L10.2, R35.1, R74.2; also elsewhere on the board
CHG: R16.1, U9.9 (~CHG); also elsewhere on the board
FUEL_GAUGE_~ALRT: R35.2, U12.5 (~ALRT); also elsewhere on the board
GND: C50.2, C57.2, C58.2, C73.2, C94.2, C95.2, C116.2, J5.2, J5.MP (MountPin), R11.1, R12.1, R13.1, R14.2, R75.1, SW3.3 (C), U9.4 (~CE), U9.6 (EN1), U9.8 (VSS), U9.14 (TMR), U9.17 (VSS), U11.2 (GND), U12.1 (CTG), U12.4 (GND), U12.6 (QSTRT), U12.9 (GND); also elsewhere on the board
I2C2_SCL: U12.7 (SCL); also elsewhere on the board
I2C2_SDA: U12.8 (SDA); also elsewhere on the board
LED_CHG: R16.2; also elsewhere on the board
unnamed: SW3.2 (B), U11.1 (EN)
unnamed: R11.2, U9.12 (ILIM)
unnamed: R12.2, U9.16 (ISET)
unnamed: R13.2, U9.15 (ITERM)
unnamed: R14.1, U9.1 (TS)
unnamed: C117.1, R74.1, R75.2, U11.6 (FB)
unnamed: L10.1, U11.3 (SW)
VBATT: C50.1, C73.1, J5.1, U9.2 (BAT), U9.3 (BAT), U12.2 (CELL), U12.3 (VDD), VBAT1.1 (1_1)
VSYS: C58.1, C94.1, C95.1, SW3.1 (A), U9.10 (OUT), U9.11 (OUT), U11.4 (VIN), VSYS1.1 (1_1); also elsewhere on the board
VUSB: C57.1, U9.5 (EN2), U9.13 (IN); also elsewhere on the board
~PGOOD: U9.7 (~PGOOD); also elsewhere on the board

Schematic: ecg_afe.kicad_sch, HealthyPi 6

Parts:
C19, C22: 2.2n; C_0402_1005Metric
C20, C30: 470p; C_0402_1005Metric
C21, C31, C37, C80, C84, C85, C86, C87: 100nF; C_0402_1005Metric
C23: 4.7uF; C_0402_1005Metric
C32, C33, C34, C35, C88, C90: 47p; C_0402_1005Metric
C36, C39, C40, C41, C81: 1u; C_0402_1005Metric
C38: 22u; C_0805_2012Metric
C42: 1.5n; C_0402_1005Metric
C43: 47pF; C_0402_1005Metric
C82, C83, C91, C92: 1uF; C_0402_1005Metric
C151: 10uF; C_0805_2012Metric
IC1: ADS1294RIZXGR; BGA64C80P8X8_800X800X145; Manufacturer_Part_Number ADS1294RIZXGR; Mouser Part Number 595-ADS1294RIZXGR
J6: Conn_01x06_Socket; PinHeader_1x06_P2.54mm_Vertical
L8: BLM18PG600SN1; LED_0603_1608Metric
R4, R5: 40.2k; R_0402_1005Metric
R19, R20, R21, R22: 10M; R_0402_1005Metric
R23, R24, R25, R26: 22k; R_0402_1005Metric
R27: 1M; R_0402_1005Metric
R28: 22K; R_0402_1005Metric
R34, R38: 221.k; R_0402_1005Metric
R49: 4.7k; R_0402_1005Metric
R56: 0R; R_0402_1005Metric
U15: LOGO
U21: TPD6E05U06RVZ; Texas_R-PUSON-N14

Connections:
+3V3: L8.1, R20.2, R21.2; also elsewhere on the board
/ECG Frontend/ADS1294_CS: IC1.F7 (~CS); also elsewhere on the board
/ECG Frontend/ADS1294_DIN: IC1.H8 (DIN); also elsewhere on the board
/ECG Frontend/ADS1294_DOUT: IC1.E8 (DOUT); also elsewhere on the board
/ECG Frontend/ADS1294_DRDY: IC1.D6 (~DRDY); also elsewhere on the board
/ECG Frontend/ADS1294_PWDN: IC1.G5 (~PWDN); also elsewhere on the board
/ECG Frontend/ADS1294_RESET: IC1.G6 (~RESET); also elsewhere on the board
/ECG Frontend/ADS1294_SCLK: IC1.F8 (SCLK); also elsewhere on the board
/ECG Frontend/ADS1294_START: IC1.G7 (START); also elsewhere on the board
ECG_IN3_N: C32.1, C90.1, J6.2, R26.2, R34.2, U21.9 (D3+)
ECG_IN3_P: C33.1, J6.3, R25.2, U21.11 (D2-)
ECG_IN4_N: C34.1, IC1.D3 (WCT), R24.2
ECG_IN4_P: C35.1, J6.4, R23.2, U21.12 (D2+)
ECG_RA: C88.1, J6.1, R38.2, U21.8 (D3-)
ECG_RLD: C43.2, J6.6, R28.1, R49.2, U21.14 (D1+)
GND: C23.2, C32.2, C33.2, C34.2, C35.2, C36.1, C37.1, C38.1, C39.1, C40.1, C41.1, C43.1, C80.1, C81.1, C82.1, C83.1, C84.1, C85.1, C86.1, C87.1, C88.2, C90.2, C91.1, C92.1, C151.1, IC1.A5 (AVSS_1), IC1.A8 (AVSS1), IC1.B5 (AVSS_2), IC1.C5 (AVSS_3), IC1.C7 (DGND_1), IC1.D4 (AVSS_4), IC1.D5 (AVSS_5), IC1.D7 (DGND_2), IC1.E4 (RESV1), IC1.H4 (VREFN), IC1.H7 (DGND_3), R19.2, R22.2, U21.5 (GND), U21.10 (GND); also elsewhere on the board
unnamed: C19.1, R4.2
unnamed: C19.2, C30.2, C31.2
unnamed: C20.1, C21.2, C22.2
unnamed: C22.1, R5.2
unnamed: C20.2, IC1.H2 (IN1N), R21.1, R22.1
unnamed: C30.1, IC1.H1 (IN1P), R19.1, R20.1
unnamed: C21.1, IC1.G2 (IN2N), R38.1
unnamed: C31.1, IC1.G1 (IN2P), R34.1
unnamed: IC1.F2 (IN3N), R26.1
unnamed: IC1.F1 (IN3P), R25.1
unnamed: IC1.E2 (IN4N), R24.1
unnamed: IC1.E1 (IN4P), R23.1
unnamed: IC1.G4 (RESP_MODP), R4.1
unnamed: IC1.F4 (RESP__MODN), R5.1
unnamed: IC1.A3 (RLDIN), R56.2
unnamed: C42.1, IC1.C3 (RLDINV), R27.1
unnamed: C42.2, IC1.B3 (RLDOUT), R27.2, R28.2, R56.1
unnamed: C38.2, IC1.H5 (VCAP1)
unnamed: C39.2, IC1.H6 (VCAP2)
unnamed: C36.2, C40.2, IC1.B7 (VCAP3)
unnamed: C41.2, IC1.G3 (VCAP4)
unnamed: C37.2, C151.2, IC1.H3 (VREFP)
SHIELD: J6.5, R49.1, U21.13 (D1-)
VDD_ECG_AFE: C23.1, C80.2, C81.2, C82.2, C83.2, C84.2, C85.2, C86.2, C87.2, C91.2, C92.2, IC1.A1 (IN8P), IC1.A2 (IN8N), IC1.A4 (AVDD_1), IC1.A6 (AVDD_2), IC1.A7 (AVDD1), IC1.B1 (IN7P), IC1.B2 (IN7N), IC1.B4 (AVDD_3), IC1.B6 (AVDD_4), IC1.B8 (CLKSEL), IC1.C1 (IN6P), IC1.C2 (IN6N), IC1.C6 (AVDD_5), IC1.C8 (DVDD_1), IC1.D1 (IN5P), IC1.D2 (IN5N), IC1.D8 (DVDD_2), L8.2

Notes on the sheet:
BLM18PG600SN1

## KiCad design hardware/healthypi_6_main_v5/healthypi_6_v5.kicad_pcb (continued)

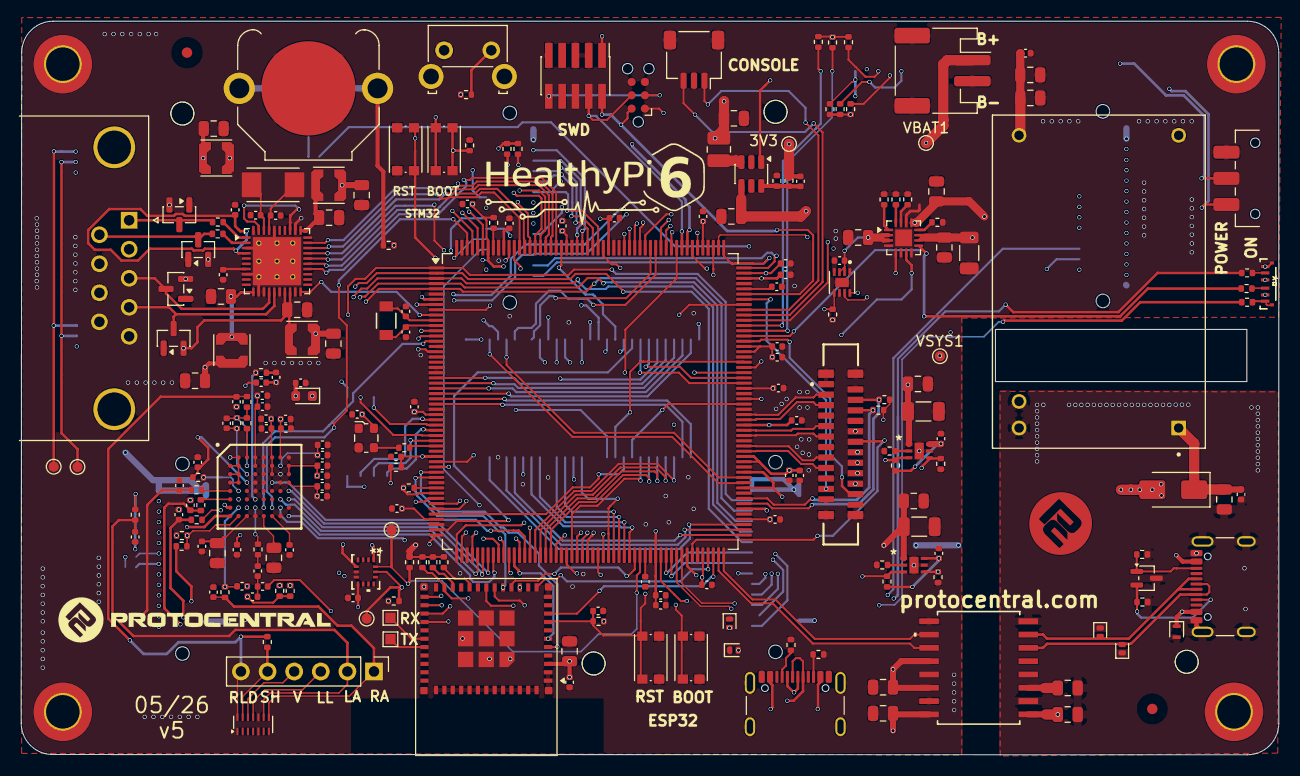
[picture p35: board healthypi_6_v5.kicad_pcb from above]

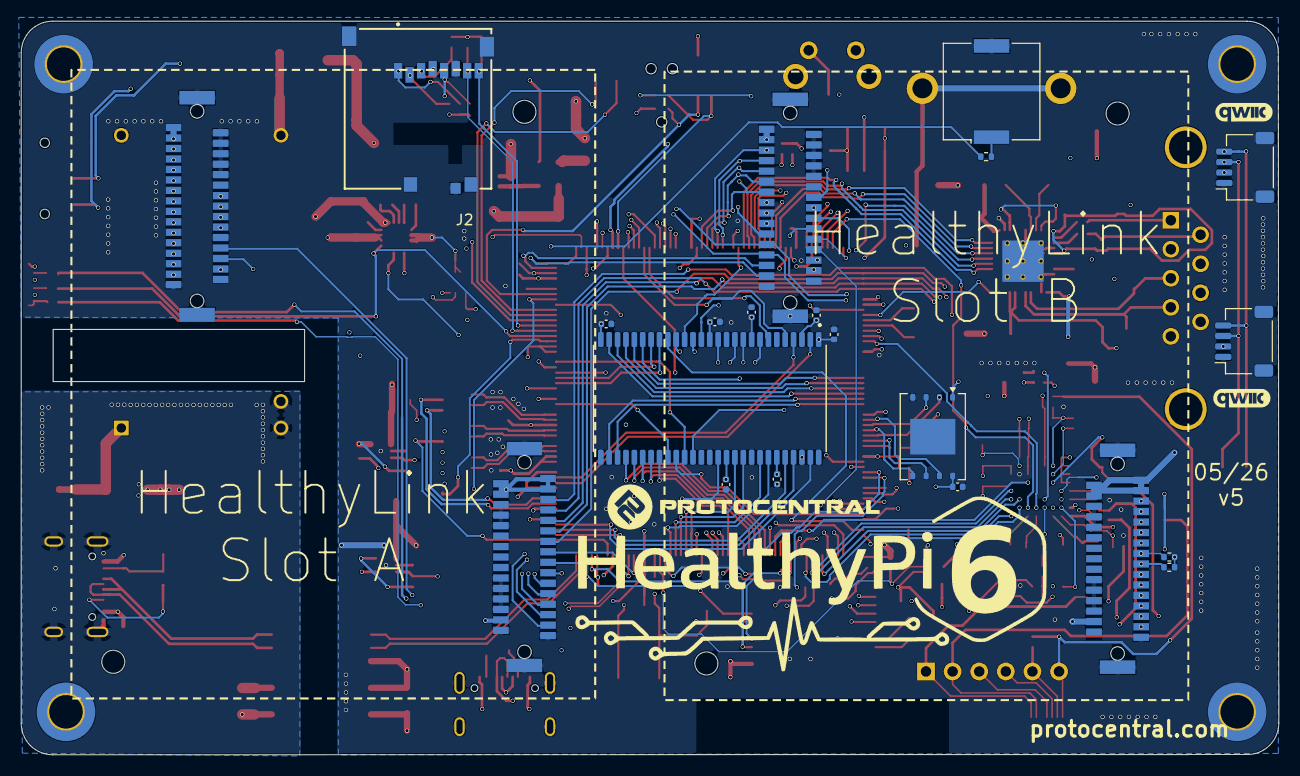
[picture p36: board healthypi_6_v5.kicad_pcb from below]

Board: 6 copper layers, 120.0 x 70.0 mm, 240 parts (17 on the bottom side), 241 nets.

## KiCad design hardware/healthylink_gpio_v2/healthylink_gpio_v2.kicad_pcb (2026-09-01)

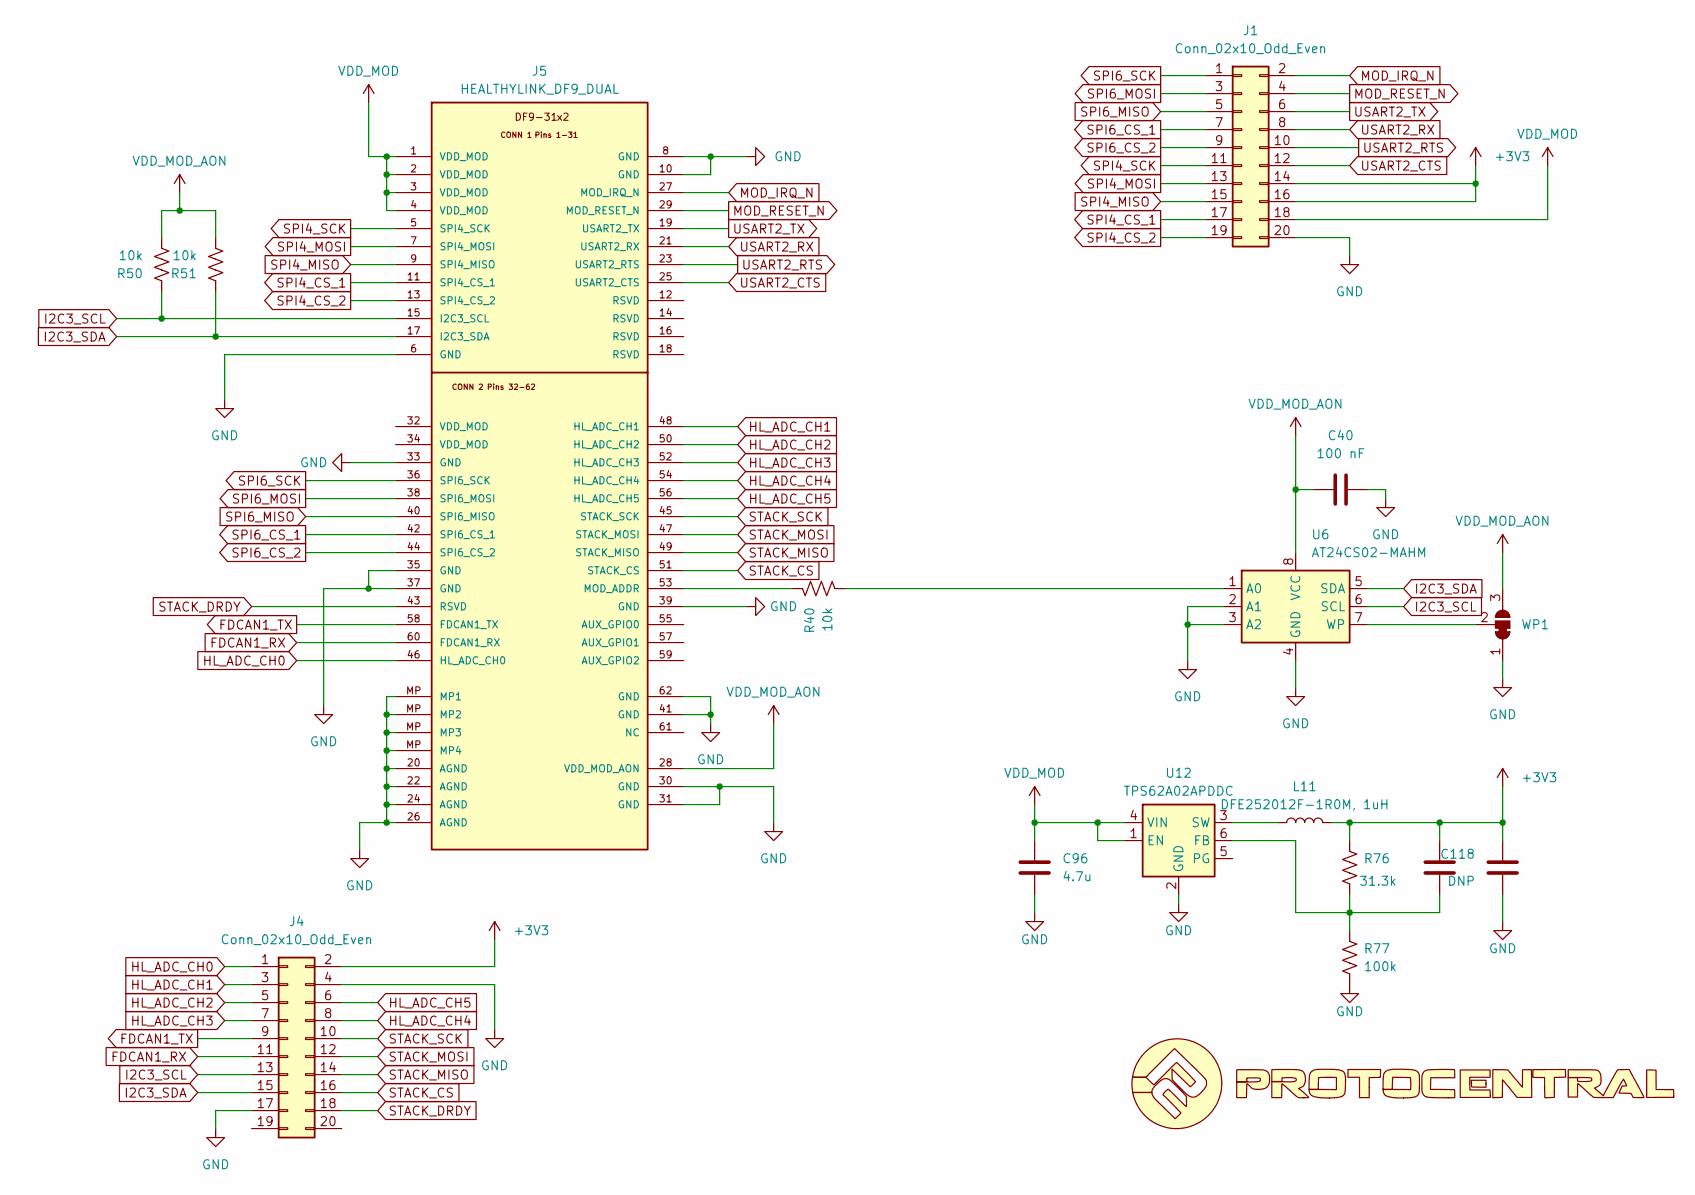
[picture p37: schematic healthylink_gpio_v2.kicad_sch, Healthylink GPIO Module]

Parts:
C40: 100 nF; C_0402_1005Metric
C96: 4.7u; C_0805_2012Metric
C118: DNP; C_0402_1005Metric
C119: 22u; C_0805_2012Metric
J1, J4: Conn_02x10_Odd_Even; PinSocket_2x10_P2.54mm_Horizontal
J5: HEALTHYLINK_DF9_DUAL; healthylink_df9_module
L11: DFE252012F-1R0M, 1uH; L_1008_2520Metric
R40, R50, R51: 10k; R_0402_1005Metric
R76: 31.3k; R_0402_1005Metric
R77: 100k; R_0402_1005Metric
U4: LOGO
U6: AT24CS02-MAHM; DFN-8-1EP_3x2mm_P0.5mm_EP1.3x1.5mm
U12: TPS62A02APDDC; SOT-23-6
WP1: SolderJumper_3_Bridged12; SolderJumper-3_P1.3mm_Bridged12_RoundedPad1.0x1.5mm

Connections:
+3V3: C118.2, C119.1, J1.14, J1.16, J4.2, L11.2, R76.2
FDCAN1_RX: J4.11, J5.60 (FDCAN1_RX)
FDCAN1_TX: J4.9, J5.58 (FDCAN1_TX)
GND: C40.1, C96.2, C119.2, J1.20, J4.4, J4.17, J5.6 (GND), J5.8 (GND), J5.10 (GND), J5.20 (AGND), J5.22 (AGND), J5.24 (AGND), J5.26 (AGND), J5.30 (GND), J5.31 (GND), J5.33 (GND), J5.35 (GND), J5.37 (GND), J5.39 (GND), J5.41 (GND), J5.62 (GND), J5.MP (MP1), R77.1, U6.2 (A1), U6.3 (A2), U6.4 (GND), U6.9 (GND), U12.2 (GND), WP1.1 (A)
HL_ADC_CH0: J4.1, J5.46 (HL_ADC_CH0)
HL_ADC_CH1: J4.3, J5.48 (HL_ADC_CH1)
HL_ADC_CH2: J4.5, J5.50 (HL_ADC_CH2)
HL_ADC_CH3: J4.7, J5.52 (HL_ADC_CH3)
HL_ADC_CH4: J4.8, J5.54 (HL_ADC_CH4)
HL_ADC_CH5: J4.6, J5.56 (HL_ADC_CH5)
I2C3_SCL: J4.13, J5.15 (I2C3_SCL), R50.1, U6.6 (SCL)
I2C3_SDA: J4.15, J5.17 (I2C3_SDA), R51.1, U6.5 (SDA)
MOD_IRQ_N: J1.2, J5.27 (MOD_IRQ_N)
MOD_RESET_N: J1.4, J5.29 (MOD_RESET_N)
unnamed: J5.53 (MOD_ADDR), R40.1
unnamed: R40.2, U6.1 (A0)
unnamed: U6.7 (WP), WP1.2 (C)
unnamed: C118.1, R76.1, R77.2, U12.6 (FB)
unnamed: L11.1, U12.3 (SW)
SPI4_CS_1: J1.17, J5.11 (SPI4_CS_1)
SPI4_CS_2: J1.19, J5.13 (SPI4_CS_2)
SPI4_MISO: J1.15, J5.9 (SPI4_MISO)
SPI4_MOSI: J1.13, J5.7 (SPI4_MOSI)
SPI4_SCK: J1.11, J5.5 (SPI4_SCK)
SPI6_CS_1: J1.7, J5.42 (SPI6_CS_1)
SPI6_CS_2: J1.9, J5.44 (SPI6_CS_2)
SPI6_MISO: J1.5, J5.40 (SPI6_MISO)
SPI6_MOSI: J1.3, J5.38 (SPI6_MOSI)
SPI6_SCK: J1.1, J5.36 (SPI6_SCK)
STACK_CS: J4.16, J5.51 (STACK_CS)
STACK_DRDY: J4.18, J5.43 (RSVD)
STACK_MISO: J4.14, J5.49 (STACK_MISO)
STACK_MOSI: J4.12, J5.47 (STACK_MOSI)
STACK_SCK: J4.10, J5.45 (STACK_SCK)
USART2_CTS: J1.12, J5.25 (USART2_CTS)
USART2_RTS: J1.10, J5.23 (USART2_RTS)
USART2_RX: J1.8, J5.21 (USART2_RX)
USART2_TX: J1.6, J5.19 (USART2_TX)
VDD_MOD: C96.1, J1.18, J5.1 (VDD_MOD), J5.2 (VDD_MOD), J5.3 (VDD_MOD), J5.4 (VDD_MOD), U12.1 (EN), U12.4 (VIN)
VDD_MOD_AON: C40.2, J5.28 (VDD_MOD_AON), R50.2, R51.2, U6.8 (VCC), WP1.3 (B)

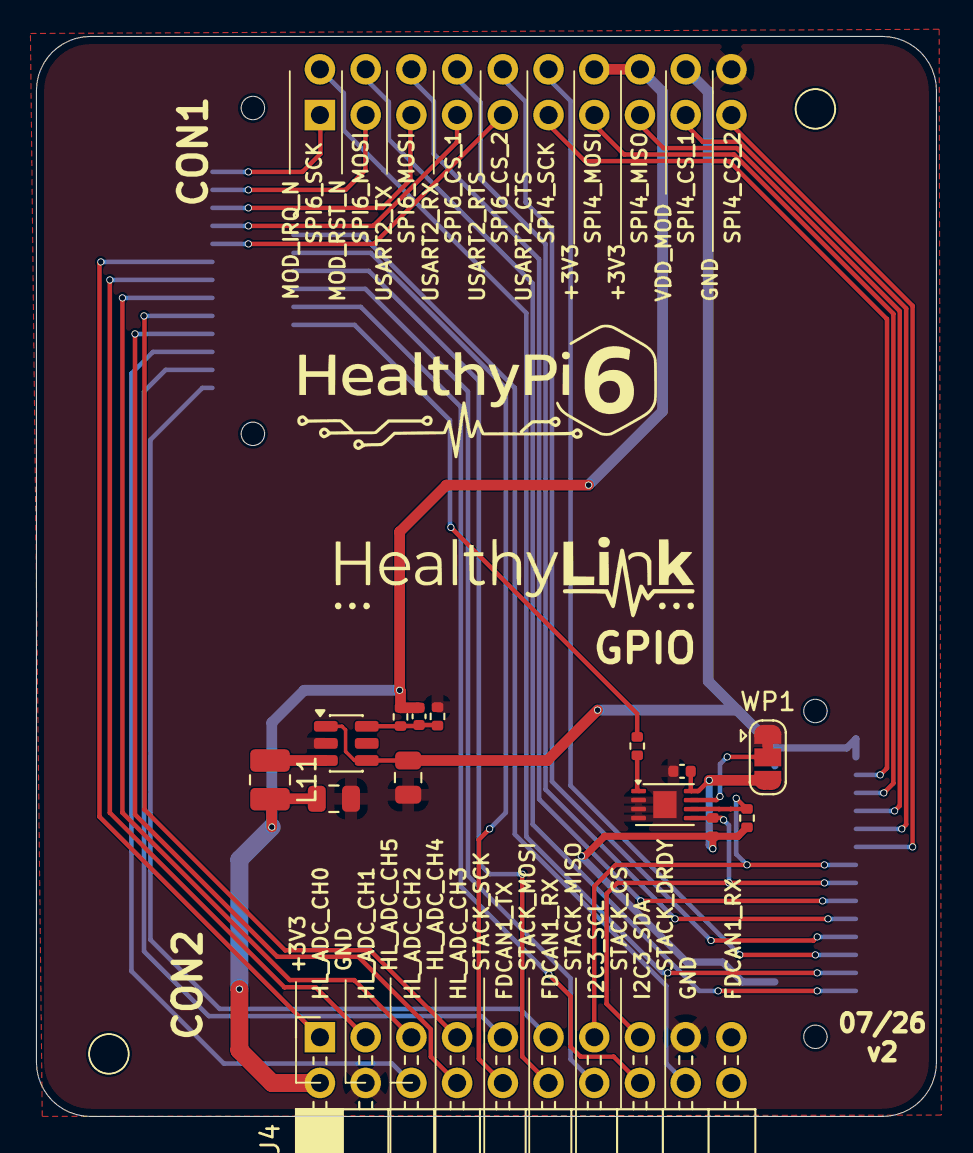
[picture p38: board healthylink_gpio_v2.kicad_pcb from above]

Board: 2 copper layers, 50.0 x 60.0 mm, 16 parts (1 on the bottom side), 40 nets.

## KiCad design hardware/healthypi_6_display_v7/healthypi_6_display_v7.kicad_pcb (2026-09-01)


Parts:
C1: 2.2uF; C_0402_1005Metric
C3, C4: 1uF; C_0402_1005Metric
C5: 100nF; C_0402_1005Metric
H1: MountingHole_Pad_MP; MountingHole_3.2mm_M3_Pad
H2, H3, H4: MountingHole_Pad_MP; MountingHole_3.2mm_M3_ISO14580_Pad
J5: Conn_01x06_Socket; TE_2328702-6
J6: 5047543120; TE_3-2328724-1
J7: GCT_FFC2A32-24-T; FFC2B3524T
L2: VLS3012ET-220M; L_Sunlord_SWPA3012S
R1: 10R; R_0402_1005Metric
R2, R3, R4, R5: 10K; R_0402_1005Metric
U1: TPS61158DRVR; DRV6_1P6X1_TEX_38825256
U2: LOGO

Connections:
+3V3: C1.1, C4.1, C5.1, J5.6, J6.6, J6.8, J7.14, J7.16, J7.18, L2.1, R2.1, R3.1, R4.1, R5.1, U1.2 (VIN)
DSI_CKN: J6.23, J7.9
DSI_CKP: J6.24, J7.11
DSI_D0N: J6.17, J7.15
DSI_D0P: J6.18, J7.17
DSI_D1N: J6.20, J7.3
DSI_D1P: J6.21, J7.5
GND: C1.2, C3.2, C4.2, C5.2, H1.1 (1_1), H2.1 (1_1), H3.1 (1_1), H4.1 (1_1), J5.5, J6.1, J6.9, J6.16, J6.19, J6.22, J6.25, J6.28, J6.31, J7.1, J7.2, J7.7, J7.8, J7.13, J7.19, J7.23, J7.24, J7.MP (MountPin), R1.2, U1.5 (GND), U1.7 (EPAD)
LEDA: C3.1, J6.15, U1.3 (VOUT)
LEDK: J6.14, R1.1, U1.4 (FB)
MIPI_BKL: J7.22, U1.1 (CTRL)
MIPI_RST: J6.10, J7.21
MIPI_TE: J6.11, J7.20
unnamed: L2.2, U1.6 (LX)
TP_INT: J5.2, J7.10, R2.2
TP_RST: J5.1, J7.12, R5.2
TP_SCL: J5.3, J7.4, R3.2
TP_SDA: J5.4, J7.6, R4.2


Board: 2 copper layers, 60.0 x 33.0 mm, 18 parts (0 on the bottom side), 18 nets.

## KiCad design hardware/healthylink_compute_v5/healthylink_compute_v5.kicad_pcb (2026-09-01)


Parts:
C40: 100 nF; C_0402_1005Metric
J5: HEALTHYLINK_DF9_DUAL; healthylink_df9_module
R35, R38: 0R; R_0402_1005Metric
R40, R50, R51: 10k; R_0402_1005Metric
U6: AT24CS02-MAHM; DFN-8-1EP_3x2mm_P0.5mm_EP1.3x1.5mm
U18: LOGO
WP1: SolderJumper_3_Bridged12; SolderJumper-3_P1.3mm_Bridged12_RoundedPad1.0x1.5mm

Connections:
GND: C40.1, J5.6 (GND), J5.8 (GND), J5.10 (GND), J5.20 (AGND), J5.22 (AGND), J5.24 (AGND), J5.26 (AGND), J5.30 (GND), J5.31 (GND), J5.33 (GND), J5.35 (GND), J5.37 (GND), J5.39 (GND), J5.41 (GND), J5.62 (GND), J5.MP (MP3), R35.1, R38.1, U6.4 (GND), U6.9 (GND), WP1.1 (A); also elsewhere on the board
I2C3_SCL: J5.15 (I2C3_SCL), R50.1, U6.6 (SCL)
I2C3_SDA: J5.17 (I2C3_SDA), R51.1, U6.5 (SDA)
MOD_IRQ_N: J5.27 (MOD_IRQ_N); also elsewhere on the board
MOD_RESET_N: J5.29 (MOD_RESET_N); also elsewhere on the board
N6_SPI5_MISO: J5.9 (SPI4_MISO); also elsewhere on the board
N6_SPI5_MOSI: J5.7 (SPI4_MOSI); also elsewhere on the board
N6_SPI5_NSS: J5.11 (SPI4_CS_1); also elsewhere on the board
N6_SPI5_SCK: J5.5 (SPI4_SCK); also elsewhere on the board
N6_USART1_CTS: J5.23 (USART2_RTS); also elsewhere on the board
N6_USART1_RTS: J5.25 (USART2_CTS); also elsewhere on the board
N6_USART1_RX: J5.19 (USART2_TX); also elsewhere on the board
N6_USART1_TX: J5.21 (USART2_RX); also elsewhere on the board
unnamed: J5.53 (MOD_ADDR), R40.1
unnamed: R40.2, U6.1 (A0)
unnamed: R35.2, U6.2 (A1)
unnamed: R38.2, U6.3 (A2)
unnamed: U6.7 (WP), WP1.2 (C)
STACK_CS: J5.51 (STACK_CS); also elsewhere on the board
STACK_DRDY: J5.43 (RSVD); also elsewhere on the board
STACK_MISO: J5.49 (STACK_MISO); also elsewhere on the board
STACK_MOSI: J5.47 (STACK_MOSI); also elsewhere on the board
STACK_SCK: J5.45 (STACK_SCK); also elsewhere on the board
VDD_MOD: J5.1 (VDD_MOD), J5.2 (VDD_MOD), J5.3 (VDD_MOD), J5.4 (VDD_MOD); also elsewhere on the board
VDD_MOD_AON: C40.2, J5.28 (VDD_MOD_AON), R50.2, R51.2, U6.8 (VCC), WP1.3 (B)


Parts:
C10, C12, C14: 4.7uF; C_0805_2012Metric
C11, C13, C17: 100 nF; C_0402_1005Metric
C27: 10n; C_0402_1005Metric
C64, C65: 12pF; C_0402_1005Metric
D5: BAT60JFILM; D_SOD-323
IC2: MX25UM51245GXDI00-TR; BGA24C100P5X5_600X800X120; Mouser Part Number 95-25UM51245GXDITR
R8, R13, R14, R18: 10k; R_0402_1005Metric
R12, R16: 1k; R_0402_1005Metric
R17: 200R; R_0402_1005Metric
R21: 0R; R_0402_1005Metric
R30: DNP; R_0402_1005Metric
SW1: SW_Push; SW_Push_1P1T_NO_CK_KMR2
SW2: SW_DIP_x02; SW_DS04-254-2-02BK-SMT
U4: STM32N657I0H3Q; VFBGA178_12X12_STM
U23: LOGO
XTAL2: ECS-.327-12.5-34B-TR; Crystal_SMD_MicroCrystal_CC8V-T1A-2Pin_2.0x1.2mm_HandSolder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

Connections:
BOOT0: R13.1, SW2.1, U4.D3 (BOOT0)
BOOT1: R14.1, SW2.2; also elsewhere on the board
CSI_CKN: U4.N3 (CSI_CKN); also elsewhere on the board
CSI_CKP: U4.P3 (CSI_CKP); also elsewhere on the board
CSI_D0N: U4.N4 (CSI_D0N); also elsewhere on the board
CSI_D0P: U4.P4 (CSI_D0P); also elsewhere on the board
CSI_D1N: U4.N2 (CSI_D1N); also elsewhere on the board
CSI_D1P: U4.P2 (CSI_D1P); also elsewhere on the board
GND: C10.2, C11.2, C12.2, C13.2, C14.2, C17.2, C27.2, C64.1, C65.1, IC2.B3 (GND), IC2.C1 (VSSQ_1), IC2.E5 (VSSQ_2), R13.2, R14.2, R17.1, SW1.2; also elsewhere on the board
N6_PWR_ON_OUT: U4.E3 (PWR_ON); also elsewhere on the board
NRST: C27.1, D5.1 (K), R30.2, SW1.1, U4.E4 (NRST); also elsewhere on the board
unnamed: D5.2 (A), IC2.A4 (RESET#), R18.2
unnamed: IC2.A5 (ECS#), R8.1
unnamed: R12.2, SW2.4
unnamed: R16.2, SW2.3
unnamed: R17.2, U4.N5 (CSI_REXT)
unnamed: C65.2, U4.B1 (PC14-OSC32_IN), XTAL2.1
unnamed: C64.2, U4.C1 (PC15-OSC32_OUT), XTAL2.2
unnamed: R21.2, U4.A1 (PDR_ON)
OSPI_CLK: IC2.B2 (SCLK), U4.K12 (PN6-XSPIM_P2_CLK)
OSPI_DQS0: IC2.C3 (DQS), U4.M13 (PN0-XSPIM_P2_DQS0)
OSPI_IO0: IC2.D3 (SIO0), U4.L13 (PN2-XSPIM_P2_IO0)
OSPI_IO1: IC2.D2 (SIO1), U4.N13 (PN3-XSPIM_P2_IO1)
OSPI_IO2: IC2.C4 (SIO2), U4.J13 (PN4-XSPIM_P2_IO2)
OSPI_IO3: IC2.D4 (SIO3), U4.K14 (PN5-XSPIM_P2_IO3)
OSPI_IO4: IC2.D5 (SIO4), U4.J14 (PN8-XSPIM_P2_IO4)
OSPI_IO5: IC2.E3 (SIO5), U4.L14 (PN9-XSPIM_P2_IO5)
OSPI_IO6: IC2.E2 (SIO6), U4.M14 (PN10-XSPIM_P2_IO6)
OSPI_IO7: IC2.E1 (SIO7), U4.N14 (PN11-XSPIM_P2_IO7)
OSPI_NCS: IC2.C2 (CS#), U4.P13 (PN1)
UCPD1_CC1: U4.A6 (UCPD1_CC1)
UCPD1_CC2: U4.B6 (UCPD1_CC2)
USB_D+: U4.B5 (OTG1_HSDP-USB1_OTG_HS_DP); also elsewhere on the board
USB_D-: U4.A5 (OTG1_HSDM-USB1_OTG_HS_DM); also elsewhere on the board
VDD_1V8AON: R21.1; also elsewhere on the board
VDD_3V3AON: R12.1, R16.1, R30.1; also elsewhere on the board
VDD_FLASH: C10.1, C11.1, C12.1, C13.1, C14.1, C17.1, IC2.B4 (VCC), IC2.D1 (VCCQ_1), IC2.E4 (VCCQ_2), R8.2, R18.1; also elsewhere on the board


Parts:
C5, C6, C7, C8, C9, C43: 1u; C_0402_1005Metric
C15: 4.7u; C_0402_1005Metric
C16: 3.3n; C_0402_1005Metric
C18, C19, C20, C21: 22u; C_0805_2012Metric
C29, C30, C31, C32: 10u; C_0402_1005Metric
C33, C34, C35, C36, C37, C38, C39, C41, C42: 100n; C_0402_1005Metric
L1: 1.0uH; L_1206_3216Metric
L8: BLM15EG121SN1D; L_0402_1005Metric
U4: STM32N657I0H3Q; VFBGA178_12X12_STM
U22: LOGO

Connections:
GND: C5.2, C6.2, C7.2, C8.2, C9.2, C15.1, C16.1, C18.1, C19.1, C20.1, C21.1, C29.2, C30.2, C31.2, C32.2, C33.2, C34.2, C35.2, C36.2, C37.2, C38.2, C39.2, C41.2, C42.2, C43.2, U4.A14 (VSS), U4.E2 (VSSAPMU), U4.E7 (VSS), U4.F1 (VSSSMPS), U4.F2 (VSSSMPS), U4.F3 (VSSSMPS), U4.F4 (VSSSMPS), U4.F5 (VSSAON), U4.F10 (VSS), U4.H10 (VSS), U4.H11 (VSS), U4.K5 (VSS), U4.K10 (VSS), U4.M4 (VSSA), U4.N1 (VREF-), U4.P1 (VSS), U4.P14 (VSS); also elsewhere on the board
unnamed: C16.2, L1.2, U4.G1 (VLXSMPS), U4.G2 (VLXSMPS), U4.G3 (VLXSMPS), U4.G4 (VLXSMPS)
unnamed: C15.2, U4.D1 (V08CAP)
unnamed: C42.1, L8.1, U4.E1 (VDDA18PMU)
VDDA_1V8: U4.D4 (VDDA18USB), U4.M1 (VREF+), U4.M3 (VDDA18ADC), U4.P5 (VDDA18CSI); also elsewhere on the board
VDDSMPS_1V8: C29.1, C30.1, C31.1, C32.1, L8.2, U4.H1 (VDDSMPS), U4.H2 (VDDSMPS), U4.H3 (VDDSMPS), U4.H4 (VDDSMPS); also elsewhere on the board
VDD_1V8AON: C36.1, C37.1, C41.1, U4.E5 (VDDA18AON), U4.J10 (VDDIO3), U4.J11 (VDDIO3), U4.L4 (VDDA18PLL); also elsewhere on the board
VDD_3V3: C43.1, U4.A4 (VDD33USB); also elsewhere on the board
VDD_3V3AON: C33.1, C34.1, C35.1, C38.1, C39.1, U4.C2 (VBAT), U4.E8 (VDDIO4), U4.E9 (VDDIO4), U4.G10 (VDD), U4.G11 (VDD), U4.G12 (VDD); also elsewhere on the board
VDD_CORE: C5.1, C6.1, C7.1, C8.1, C9.1, C18.2, C19.2, C20.2, C21.2, L1.1, U4.D2 (VFBSMPS), U4.K6 (VDDCORE), U4.K7 (VDDCORE), U4.K8 (VDDCORE), U4.K9 (VDDCORE), U4.L7 (VDDCORE), U4.N6 (VDDCSI)

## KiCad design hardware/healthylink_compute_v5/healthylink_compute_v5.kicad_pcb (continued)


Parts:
C3, C4: 8.2p; C_0402_1005Metric
D3: RED; LED_0603_1608Metric
D4: BLUE; LED_0603_1608Metric
J14: Conn_02x05_Odd_Even; PinHeader_2x05_P1.27mm_Vertical_SMD
J22: SM03B-SRSS-TB; JST_SH_SM03B-SRSS-TB_1x03-1MP_P1.00mm_Horizontal
R25, R26: 1k; R_0402_1005Metric
U4: STM32N657I0H3Q; VFBGA178_12X12_STM
U21: LOGO
Y2: NX1612SA-48MHZ-EXS00A-CS13734; Crystal_1612

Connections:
BOOT1: U4.L8 (PA6); also elsewhere on the board
BOOT_LED: D3.1 (K), U4.N10 (PG10)
CSI_IO0: U4.P10 (PA0); also elsewhere on the board
CSI_IO1: U4.P11 (PB10); also elsewhere on the board
CSI_SCL: U4.P8 (PA8); also elsewhere on the board
CSI_SDA: U4.M7 (PA9); also elsewhere on the board
GND: C3.2, C4.2, J14.3, J14.5, J14.9, J22.2, J22.MP, Y2.2, Y2.4; also elsewhere on the board
GP_LED: D4.1 (K), U4.P9 (PG13)
MOD_IRQ_N: U4.E12 (PB3); also elsewhere on the board
MOD_RESET_N: U4.E13 (PB2); also elsewhere on the board
N6_SPI5_MISO: U4.B13 (PD4); also elsewhere on the board
N6_SPI5_MOSI: U4.L2 (PF11); also elsewhere on the board
N6_SPI5_NSS: U4.K11 (PA3); also elsewhere on the board
N6_SPI5_SCK: U4.N9 (PG12); also elsewhere on the board
N6_USART1_CTS: U4.K2 (PF14-USART1_CTS); also elsewhere on the board
N6_USART1_RTS: U4.K3 (PF15-USART1_RTS); also elsewhere on the board
N6_USART1_RX: U4.L3 (PF12); also elsewhere on the board
N6_USART1_TX: U4.M2 (PF13); also elsewhere on the board
N6_USART2_RX: J22.1, U4.A11 (PD6)
N6_USART2_TX: J22.3, U4.D14 (PD5)
NRST: J14.10; also elsewhere on the board
unnamed: D3.2 (A), R25.2
unnamed: D4.2 (A), R26.2
unnamed: C4.1, U4.B7 (PH0-OSC_IN), Y2.3
unnamed: C3.1, U4.A7 (PH1-OSC_OUT), Y2.1
SD_CLK: U4.D7 (PC12); also elsewhere on the board
SD_CMD: U4.E6 (PH2); also elsewhere on the board
SD_DAT0: U4.C6 (PC8); also elsewhere on the board
SD_DAT1: U4.D6 (PC9); also elsewhere on the board
SD_DAT2: U4.D8 (PC10); also elsewhere on the board
SD_DAT3/CD: U4.C7 (PC11); also elsewhere on the board
SD_DET: U4.A8 (PC6); also elsewhere on the board
STACK_CS: U4.B9 (PE11-SPI4_NSS); also elsewhere on the board
STACK_DRDY: U4.A10 (PE6-USART1_RX); also elsewhere on the board
STACK_MISO: U4.C10 (PE13-SPI4_MISO); also elsewhere on the board
STACK_MOSI: U4.C9 (PE14-SPI4_MOSI); also elsewhere on the board
STACK_SCK: U4.D10 (PE12-SPI4_SCK); also elsewhere on the board
STAT_3V3: U4.A13 (PD3); also elsewhere on the board
TCK_SWDCLK: J14.4, U4.P6 (PA14)
TMS/SWDIO: J14.2, U4.P7 (PA13)
VDD_3V3AON: J14.1, R25.1, R26.1; also elsewhere on the board


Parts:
C95, C96, C97: 4.7u; C_0805_2012Metric
C116, C119, C121: 22u; C_0805_2012Metric
C117, C118, C120: DNP; C_0402_1005Metric
C122, C123: 1u; C_0805_2012Metric
L4, L9: BLM15EG121SN1D; L_0402_1005Metric
L10, L11, L12: DFE252012F-1R0M, 1uH; L_1008_2520Metric
R36, R37, R39, R77, R79: 100k; R_0402_1005Metric
R74, R76: 31.3k; R_0402_1005Metric
R75: 10k; R_0402_1005Metric
R78: 200k; R_0402_1005Metric
TP4, TP5, TP6, TP7, TP8: TestPoint; TestPoint_Pad_D1.0mm
U1: TPS2116DRL; DRL0008A-MFG
U2: TLV75518PDBV; SOT-23-5
U11, U12, U13: TPS62A02APDDC; SOT-23-6
U19: LOGO

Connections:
GND: C95.2, C96.2, C97.2, C116.2, C119.2, C121.2, C122.2, C123.2, R37.2, R75.1, R77.1, R79.1, U1.1 (GND), U2.2 (GND), U11.2 (GND), U12.2 (GND), U13.2 (GND); also elsewhere on the board
N6_PWR_ON_OUT: TP8.1 (1_1), U11.1 (EN), U13.1 (EN); also elsewhere on the board
unnamed: R36.2, R37.1, U1.4 (PR1)
unnamed: C117.1, R74.1, R75.2, U11.6 (FB)
unnamed: L10.1, U11.3 (SW)
unnamed: C118.1, R76.1, R77.2, U12.6 (FB)
unnamed: L11.1, U12.3 (SW)
unnamed: C120.1, R78.1, R79.2, U13.6 (FB)
unnamed: L12.1, U13.3 (SW)
STAT_3V3: R39.2, U1.8 (ST); also elsewhere on the board
VBUS: R36.1, U1.3 (VIN1), U1.5 (MODE); also elsewhere on the board
VDDA_1V8: L4.2, TP4.1 (1_1); also elsewhere on the board
VDDSMPS_1V8: C120.2, C121.1, L4.1, L9.1, L12.2, R78.2, TP7.1 (1_1); also elsewhere on the board
VDD_1V8AON: C122.1, U2.5 (OUT); also elsewhere on the board
VDD_3V3: C116.1, C117.2, L10.2, R74.2, TP6.1 (1_1); also elsewhere on the board
VDD_3V3AON: C118.2, C119.1, C123.1, L11.2, R76.2, TP5.1 (1_1), U2.1 (IN), U2.3 (EN); also elsewhere on the board
VDD_FLASH: L9.2; also elsewhere on the board
VDD_MOD: U1.6 (VIN2); also elsewhere on the board
VSYS: C95.1, C96.1, C97.1, R39.1, U1.2 (VOUT), U1.7 (VOUT), U11.4 (VIN), U12.1 (EN), U12.4 (VIN), U13.4 (VIN)


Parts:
C28: 100n; C_0402_1005Metric
CR2: ESDA25P35-1U1M; ST_QFN-2L_1.6x1.0mm
D1, D2: PESD0402-0402; D_SOD-882D
J1: Micro_SD_Card_Det1; GCT_MEM2052-00-195-00-A_REVA
J3: USB_C_Receptacle_USB2.0_16P; USB_C_Receptacle_GCT_USB4105-xx-A_16P_TopMnt_Horizontal
J4: Conn_02x10_Odd_Even; PinHeader_2x10_P1.27mm_Vertical_SMD
L3: L; L_1008_2520Metric
R7, R9: 5.1K; R_0402_1005Metric
R22, R23, R24, R28, R29: 47k; R_0402_1005Metric
U20: LOGO

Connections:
CC1: J3.A5 (CC1), R9.2
CC2: J3.B5 (CC2), R7.2
CSI_CKN: J4.4; also elsewhere on the board
CSI_CKP: J4.3; also elsewhere on the board
CSI_D0N: J4.8; also elsewhere on the board
CSI_D0P: J4.7; also elsewhere on the board
CSI_D1N: J4.12; also elsewhere on the board
CSI_D1P: J4.11; also elsewhere on the board
CSI_IO0: J4.18; also elsewhere on the board
CSI_IO1: J4.19; also elsewhere on the board
CSI_SCL: J4.16; also elsewhere on the board
CSI_SDA: J4.17; also elsewhere on the board
GND: C28.1, CR2.2, D1.1, D2.1, J1.6 (VSS), J1.10 (SHIELD), J3.A1 (GND), J3.A12 (GND), J3.B1 (GND), J3.B12 (GND), J3.S1 (SHIELD), J4.1, J4.2, J4.5, J4.6, J4.9, J4.10, J4.13, J4.14, R7.1, R9.1; also elsewhere on the board
unnamed: J3.A4 (VBUS), J3.A9 (VBUS), J3.B4 (VBUS), J3.B9 (VBUS), L3.1
SD_CLK: J1.5 (CLK); also elsewhere on the board
SD_CMD: J1.3 (CMD), R24.1; also elsewhere on the board
SD_DAT0: J1.7 (DAT0), R28.1; also elsewhere on the board
SD_DAT1: J1.8 (DAT1), R29.1; also elsewhere on the board
SD_DAT2: J1.1 (DAT2), R22.1; also elsewhere on the board
SD_DAT3/CD: J1.2 (DAT3/CD), R23.1; also elsewhere on the board
SD_DET: J1.9 (DET); also elsewhere on the board
USB_D+: D1.2, J3.A6 (D+), J3.B6 (D+); also elsewhere on the board
USB_D-: D2.2, J3.A7 (D-), J3.B7 (D-); also elsewhere on the board
VBUS: CR2.1, L3.2; also elsewhere on the board
VDD_3V3: C28.2, J1.4 (VDD), J4.20, R22.2, R23.2, R24.2, R28.2, R29.2; also elsewhere on the board



Board: 6 copper layers, 50.0 x 60.0 mm, 119 parts (24 on the bottom side), 100 nets.
